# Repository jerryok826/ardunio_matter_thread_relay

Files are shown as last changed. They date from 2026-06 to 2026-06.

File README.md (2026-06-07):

# Matter-over-Thread 4-Channel Intelligent Relay Controller

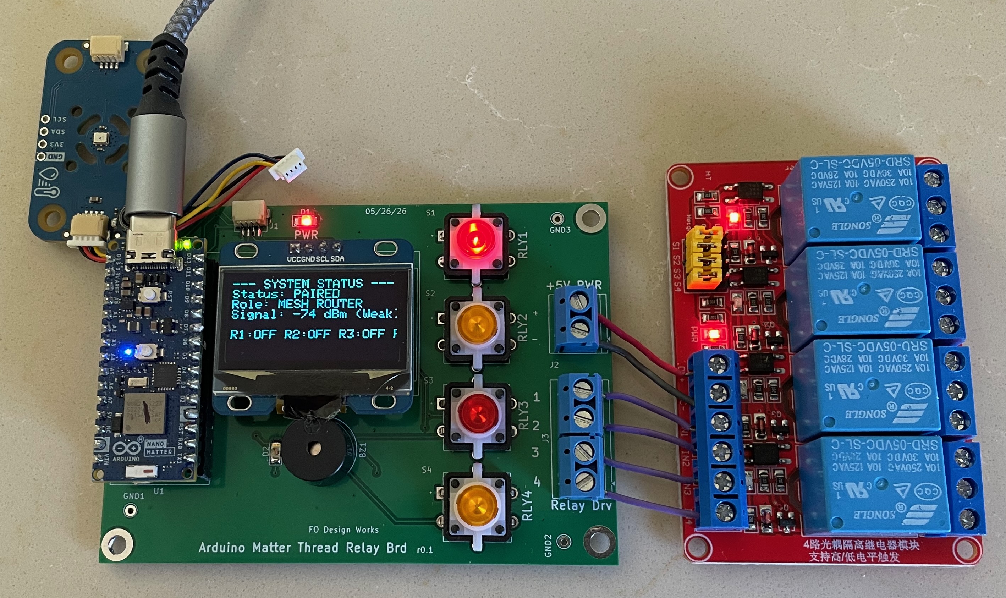
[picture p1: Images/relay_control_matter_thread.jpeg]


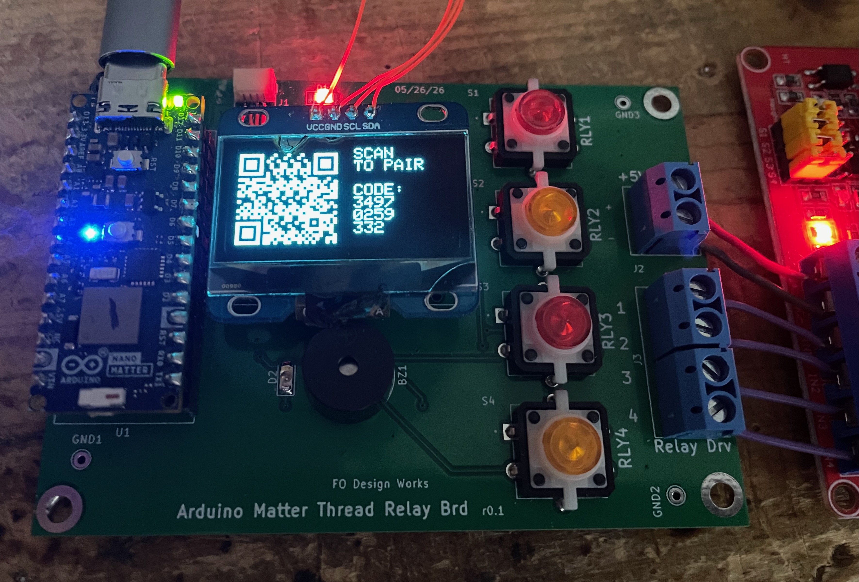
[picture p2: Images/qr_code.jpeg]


The board shown below is an Arduino Matter/Thread relay controller designed for use with an Apple HomeKit network. It uses an Arduino Nano Matter processor to control four onboard relays, which can be used to operate motors, lights, valves, or other electrical loads.

Each relay can be controlled locally using the onboard pushbuttons, allowing users to manually enable or disable individual outputs. Through the Apple Home app on an iPhone, each relay can also be monitored and controlled remotely from anywhere with internet access.

An integrated OLED display provides system status information, including Thread network signal strength. During initial setup, the display presents a QR code that can be scanned to quickly add the device to the Apple Home app.

The board also includes an I²C Qwiic connector for attaching external sensors and peripherals. For example, a rain sensor could be connected to automatically disable irrigation valves during rainfall, helping conserve water and prevent overwatering.

**Status:** The board completely supports relay control. The I²C Qwiic connector is wired wrong. There are other physical placements that need updating. So the board will be turned. Gerber files will be punished after these changes.

An industrial-grade, ultra-low-latency 4-Channel Relay Controller built using the **Arduino Nano Matter** (Silicon Labs MGM240S core). This project connects natively with Apple Home, Home Assistant, and other Matter ecosystems over a self-healing Thread mesh network.

Featuring an asynchronous hardware override architecture, non-blocking FreeRTOS thread watchdogs, and an integrated I2C OLED display that acts as a standalone **RF Survey & Walk-Testing Tool**, this project is designed for robust, long-term smart home panel automation.

---

## ✨ Key Features

- **Ecosystem Unified Build:** Native Matter protocol integration that auto-populates as four independent, sequential switch endpoints in your smart home application.
- **Zero App Dependence Override:** Local manual buttons run entirely on edge-triggered **Asynchronous Hardware Interrupts**. Relays switch locally within microseconds even if your smart home hub is offline or entirely destroyed.
- **Anti-Race Watchdog:** Implements a non-blocking 50ms throttled execution pacing engine to prevent Matter application layer data collisions and loop freezing.
- **Failsafe Boot Protection:** Firmware forces relay pins to an explicit `LOW` state prior to opening output drivers. Combined with physical pull-down networks, this eliminates clicks or accidental appliance cycles during microcontroller reboots.
- **Dual-OLED Matrix Engine:** Dynamic runtime support for both **SH1106** and **SSD1306** I2C displays via a simple preprocessor toggle.
- **Standalone RF Survey Tool:** Displays a dynamic pairing QR code on boot, then transitions automatically into a real-time system dashboard mapping your Thread Node Role and precise signal attenuation metrics (`dBm`) on a fast 3-second cycle.

---

## 🛠️ Hardware Requirements & Pinout

### Core Microcontroller
- [Arduino Nano Matter](https://arduino.cc) (Silicon Labs MGM240S)

### Supported Displays
- 0.96" I2C OLED Display (**SH1106 Recommended** for native border alignment, or SSD1306)

### Physical Netlist Connection Map

| Arduino Pin | Hardware Component | Electrical Specification / Circuit Design |
| :--- | :--- | :--- |
| **D2** | Relay 1 Trigger Output | Active-HIGH Latch (Must use 10kΩ external Pull-Down to GND) |
| **D3** | Relay 2 Trigger Output | Active-HIGH Latch (Must use 10kΩ external Pull-Down to GND) |
| **D4** | Relay 3 Trigger Output | Active-HIGH Latch (Must use 10kΩ external Pull-Down to GND) |
| **D5** | Relay 4 Trigger Output | Active-HIGH Latch (Must use 10kΩ external Pull-Down to GND) |
| **D6** | Manual Button 1 Input | Short-to-GND Momentary Switch (Relies on internal `INPUT_PULLUP`) |
| **D7** | Manual Button 2 Input | Short-to-GND Momentary Switch (Relies on internal `INPUT_PULLUP`) |
| **D8** | Manual Button 3 Input | Short-to-GND Momentary Switch (Relies on internal `INPUT_PULLUP`) |
| **D9** | Manual Button 4 Input | Short-to-GND Momentary Switch (Relies on internal `INPUT_PULLUP`) |
| **A4 / SDA**| OLED Serial Data Line | I2C Data (Include physical 4.7kΩ external Pull-Up to 3.3V) |
| **A5 / SCL**| OLED Serial Clock Line | I2C Clock (Include physical 4.7kΩ external Pull-Up to 3.3V) |
| **BTN_BUILTIN**| Factory Reset Trigger | Physical button on Nano Matter. Hold 10s to wipe Matter Fabric. |

> ⚠️ **CRITICAL DEVELOPER WARNING:** The Arduino Nano Matter GPIO pins safely output a maximum of **4mA to 8mA**. Standard mechanical relay coils draw between **70mA and 100mA**. **Do not wire relay coils directly to the Arduino pins.** You must use transistor switches (e.g., 2N2222) or optocouplers (e.g., PC817) on your custom PCB to isolate the driver currents.

---

## 💻 Firmware Installation & Configuration

### 1. Prerequisites
Ensure your Arduino IDE environment is properly updated:
1. Open the Arduino IDE, go to **Tools > Board > Boards Manager** and install the **Arduino Nano Matter** board package.
2. Go to **Tools > Manage Libraries** and install these exact dependencies:
   - `SSD1306Ascii` (by Bill Greiman)
   - `QRCode` (by Richard Moore)

### 2. IDE Compilation Configuration
Before flashing the firmware, you **must** configure the low-level stack settings:
- Go to **Tools > Protocol Stack** and select **Matter**. 
- *Note: If this is left on "None", the compiler will completely ignore all Matter initialization sequences.*

### 3. Display Selection Toggle
At the very top of the primary sketch file, uncomment the specific preprocessor definition that matches your physical OLED module hardware:

```cpp
// UNCOMMENT ONLY ONE of the options below to match your physical OLED panel:
#define DISPLAY_TYPE_SH1106      // Use this if your screen has an SH1106 controller
// #define DISPLAY_TYPE_SSD1306  // Use this if your screen has a true SSD1306 controller
```

---

## 📱 Provisioning & First-Time Setup

1. Flash the firmware to your board and open your serial monitor at **115200 baud**.
2. Upon boot, the board will automatically check its secure enclave storage rows. If it is uncommissioned, a custom **Version 3 QR Matrix** will automatically render on the left side of your OLED screen.
3. Open your native smart home app (e.g., **Apple Home**) on your iPhone.
4. Tap **Add Accessory** and point your camera at the OLED glass panel.
5. **Alternative Manual Flow:** If the camera cannot capture the display grid due to enclosure glare, tap *More Options / I Don't Have a Code*, select the module from the nearby Bluetooth list, and manually input the static 11-digit setup passcode:
   ```text
   Manual Setup Code: 3497-0259-332
   ```
6. Keep your phone close to the hardware for the first 30 seconds. The initial handshake executes over Bluetooth Low Energy (BLE) before moving the board permanently to your home's **Thread Mesh Network**.

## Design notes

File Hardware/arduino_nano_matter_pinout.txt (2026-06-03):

Module:Arduino_Nano pin out

Left Side (Pins 1–15, Antenna heading UP to USB-C)
Pin 1: D0 / TX1 (Right next to the RF Antenna)
Pin 2: D1 / RX1
Pin 3: ~RST (Reset Input)
Pin 4: GND (Ground)
Pin 5: D2
Pin 6: D3
Pin 7: D4
Pin 8: D5
Pin 9: D6
Pin 10: D7
Pin 11: D8
Pin 12: D9
Pin 13: D10
Pin 14: D11
Pin 15: D12 (Top-left corner pin right next to the USB-C port)
Right Side (Pins 16–30, USB-C heading DOWN to Antenna)
Pin 16: D13 (Top-right corner pin right next to the USB-C port)
Pin 17: +3.3V (Regulated Power Output)
Pin 18: AREF (Analog Reference Reference)
Pin 19: A0 (First Analog Input)
Pin 20: A1
Pin 21: A2
Pin 22: A3
Pin 23: A4 / SDA
Pin 24: A5 / SCL
Pin 25: A6
Pin 26: A7
Pin 27: +5V (Regulated 5V Output or USB Bus Power Input)
Pin 28: NC
Pin 29: GND (Ground 2)
Pin 30: VIN (Unregulated Power Input, bottom-right across from Pin 1)

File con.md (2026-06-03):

# Contributing to the Matter-over-Thread Relay Controller

First off, thank you for taking the time to contribute! This project is open-source, and contributions from the community help make this firmware more resilient, feature-rich, and reliable for long-term smart home industrial deployments.

As an embedded development project handling real-time networks (Matter/Thread) and low-level hardware constraints, please review the following guidelines before opening a pull request (PR).

---

## 🛡️ Core Architecture Constraints (Do Not Break)

The firmware in this repository has been heavily optimized to run reliably in an asynchronous, multi-threaded FreeRTOS environment. To ensure stability, all contributions must respect the following architectural constraints:

### 1. Strictly Non-Blocking Execution
- **Never add blocking `delay()` statements anywhere inside the `loop()` or peripheral handlers.** 
- The background Silicon Labs OpenThread engine relies on microsecond-level timing windows. Introducing blocking code starves the network stack, causing dynamic packet drops, frozen status registers, and sudden "No Response" errors in home automation applications.
- Always implement timing intervals using non-blocking tracking variables combined with `millis()` checks.

### 2. Microsecond-Level ISR Isolation
- Keep Hardware Interrupt Service Routines (`pin6_ISR` through `pin9_ISR`) as lightweight as possible. 
- Do not run calculations, serial printing, or display routines inside an active ISR thread. Simply set the volatile state tracking flag (`buttonFlags[i] = true;`) and exit, allowing the main runtime loop to handle physical pin execution.

### 3. Asynchronous Data Coupling & Throttling
- Matter network state updates (`get_onoff()`) occur asynchronously in a low-priority background thread. 
- Any code evaluating or polling smart home network clusters must operate inside a throttled window (configured natively to **50ms**). Unthrottled continuous querying forces memory race conditions, dropping local physical button signals.
- Decouple local physical pins from over-the-air network commands by using the established `shadowMatterStates` tracking array layout to filter out redundant execution loops.

---

## 🔧 Workflow Guidelines

### 1. Code Style & Conventions
- Maintain the **Manual Code Version Tracker** block at the top of the sketch to flag project iterations cleanly during debugging.
- Explicitly pass specific index boundaries (such as `[i]`) across all conditional loops and hardware array mappings. Avoid comparisons that force array decay into raw pointers, which fail silently on compilation check gates.
- Comment any adjustments made to low-level OpenThread system registers (`otInstanceInitSingle()`, etc.) to specify the network safety layout impact.

### 2. Testing Your Submissions
Before committing code or submitting a PR, your build must pass the following benchmark checks on a physical target board:
1. **Compilation Check:** Confirm the sketch compiles with zero warnings or token formatting errors in the Arduino IDE under the target board profile.
2. **Ecosystem Sync Test:** Verify that cycling a local physical push-button immediately mirrors the correct toggle state on your app dashboard within 100ms.
3. **RF Walk-Test Verification:** Ensure the 3-second non-blocking display loop updates the active dBm neighbor data accurately without stalling the local mechanical relay contacts.
4. **Decommission Safety Profile:** Verify that holding the physical user button for 10 full seconds forcefully triggers a clean fabric wipe and triggers a clean hardware system reset (`NVIC_SystemReset()`).

### 3. Opening a Pull Request
- Create a distinct topic branch for your feature or patch. Do not submit changes directly to the `main` branch.
- Structure your commit messages clearly (e.g., `fix: add explicit array indexing boundary to loop validation tracker`).
- Describe the exact hardware setup, display module configuration type (SH1106 or SSD1306), and automation hub you used during testing in your PR summary notes.

---

## 📜 Code of Conduct

By participating in this project, you agree to treat all contributors with respect, provide constructive technical feedback during code reviews, and promote collaborative open-source engineering.

Thank you for helping optimize this intelligent Matter relay node footprint!

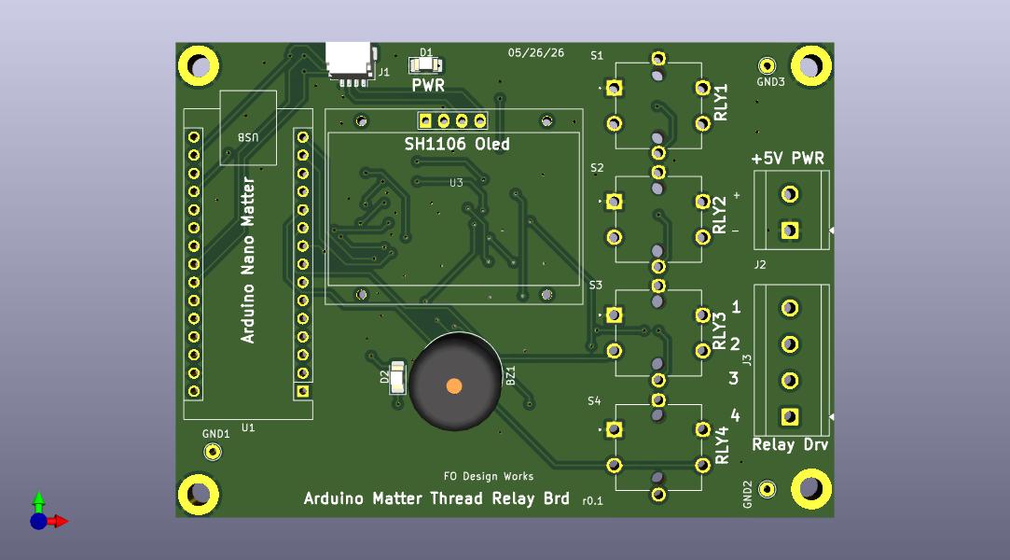
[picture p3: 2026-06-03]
Hardware/matter_thread_relay_r1.jpg

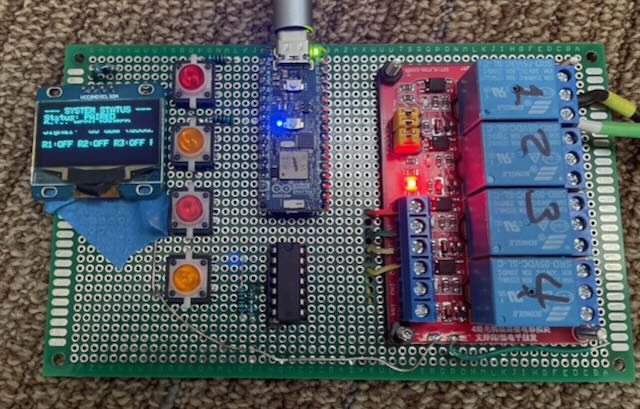
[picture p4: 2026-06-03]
Images/matter_thread_relay_3.jpeg

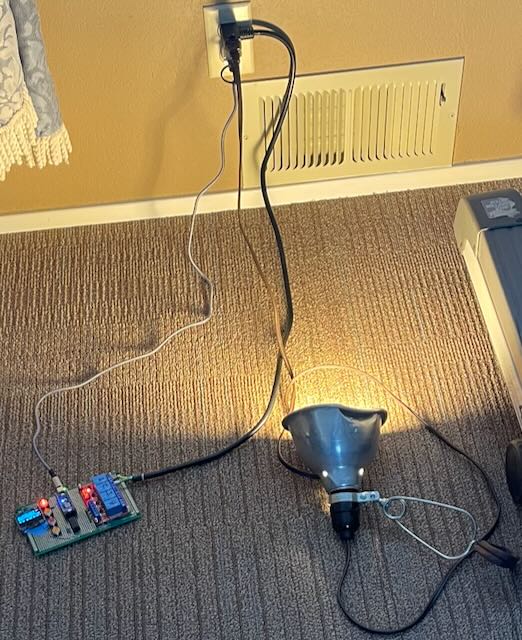
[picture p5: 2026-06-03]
Images/matter_thread_relay_4.jpeg

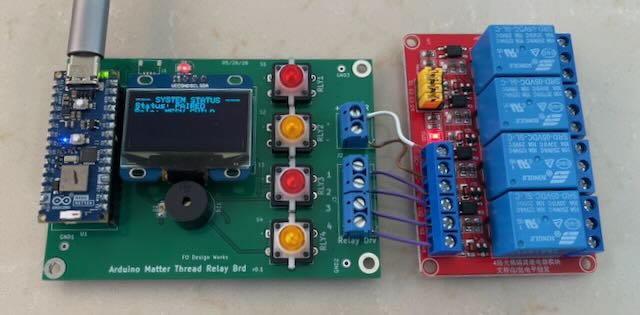
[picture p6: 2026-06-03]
Images/matter_thread_relay_1.jpeg

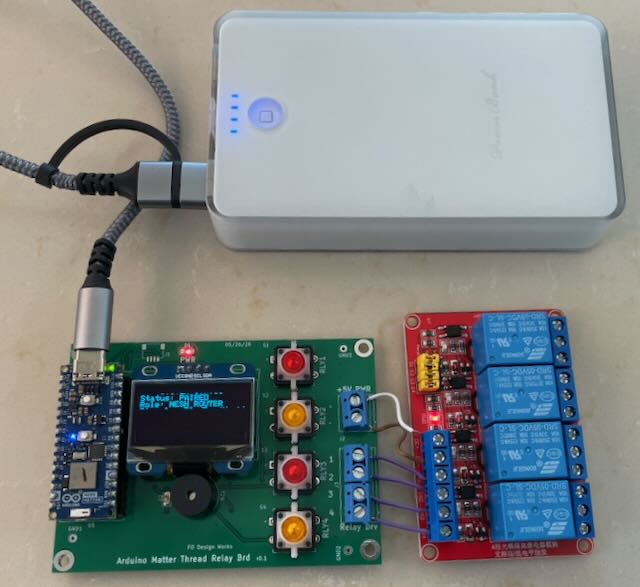
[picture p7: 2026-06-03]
Images/matter_thread_relay_2.jpeg

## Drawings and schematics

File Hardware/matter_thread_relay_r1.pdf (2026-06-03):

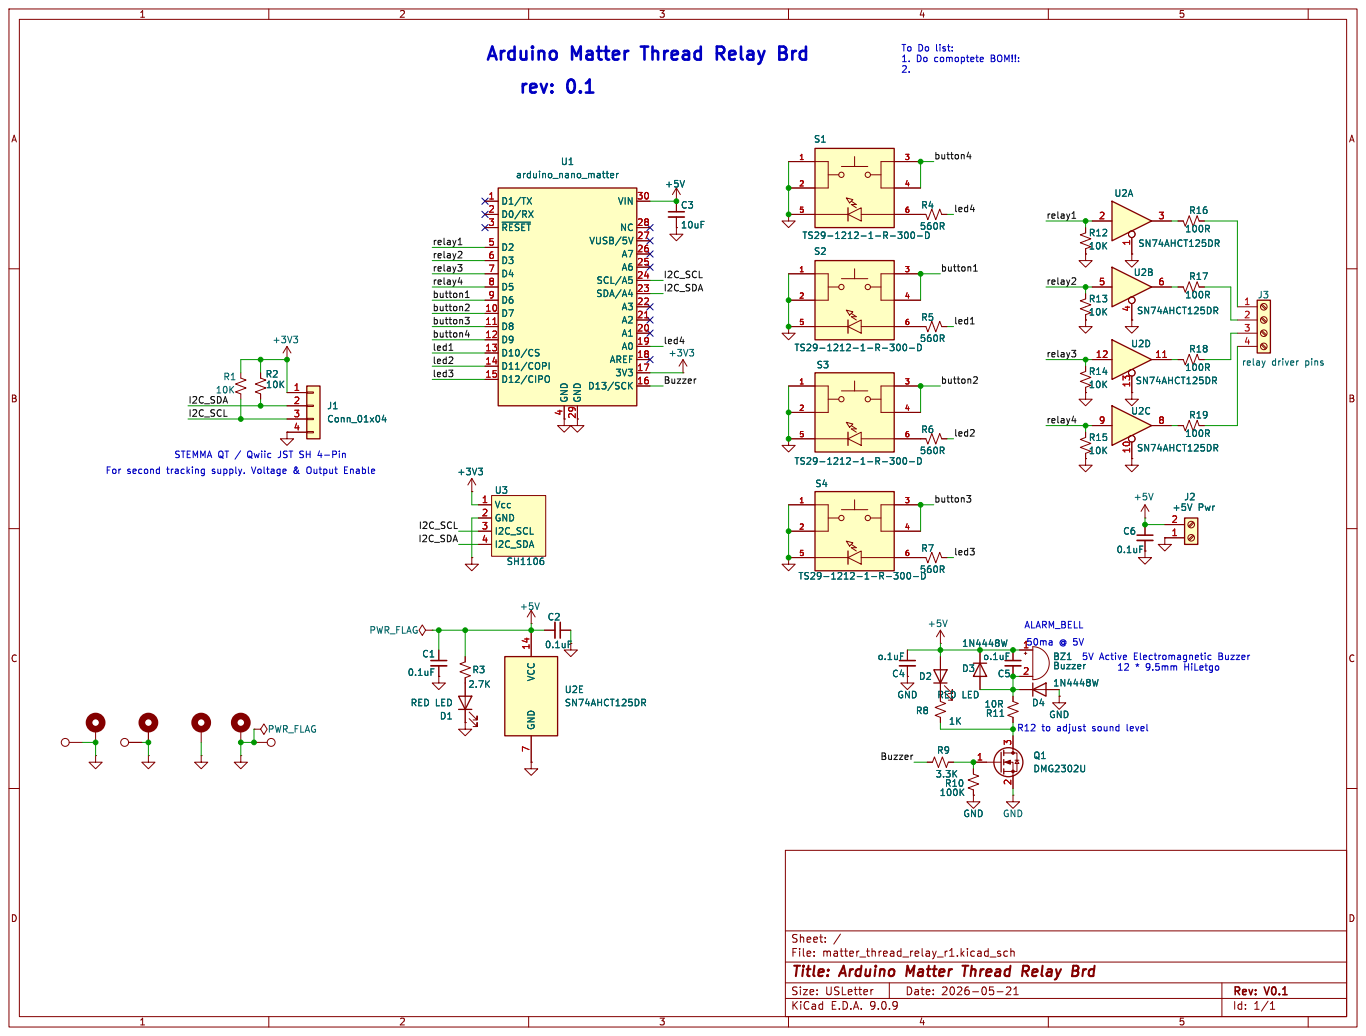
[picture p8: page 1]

button4 Buzzer Buzzer Arduino Matter Thread Relay Brd
rev: 0.1

4 GND 29 VIN 30 NC 28 VUSB/5V 27 A7 26 A6 25 SCL/A5 24 SDA/A4 23 A3 22 A2 21 A1 20 A0 19 AREF 18

STEMMA QT / Qwiic JST SH 4-Pin

File: matter_thread_relay_r1.kicad_sch Sheet: /
Id: 1/1 Title: Arduino Matter Thread Relay Brd

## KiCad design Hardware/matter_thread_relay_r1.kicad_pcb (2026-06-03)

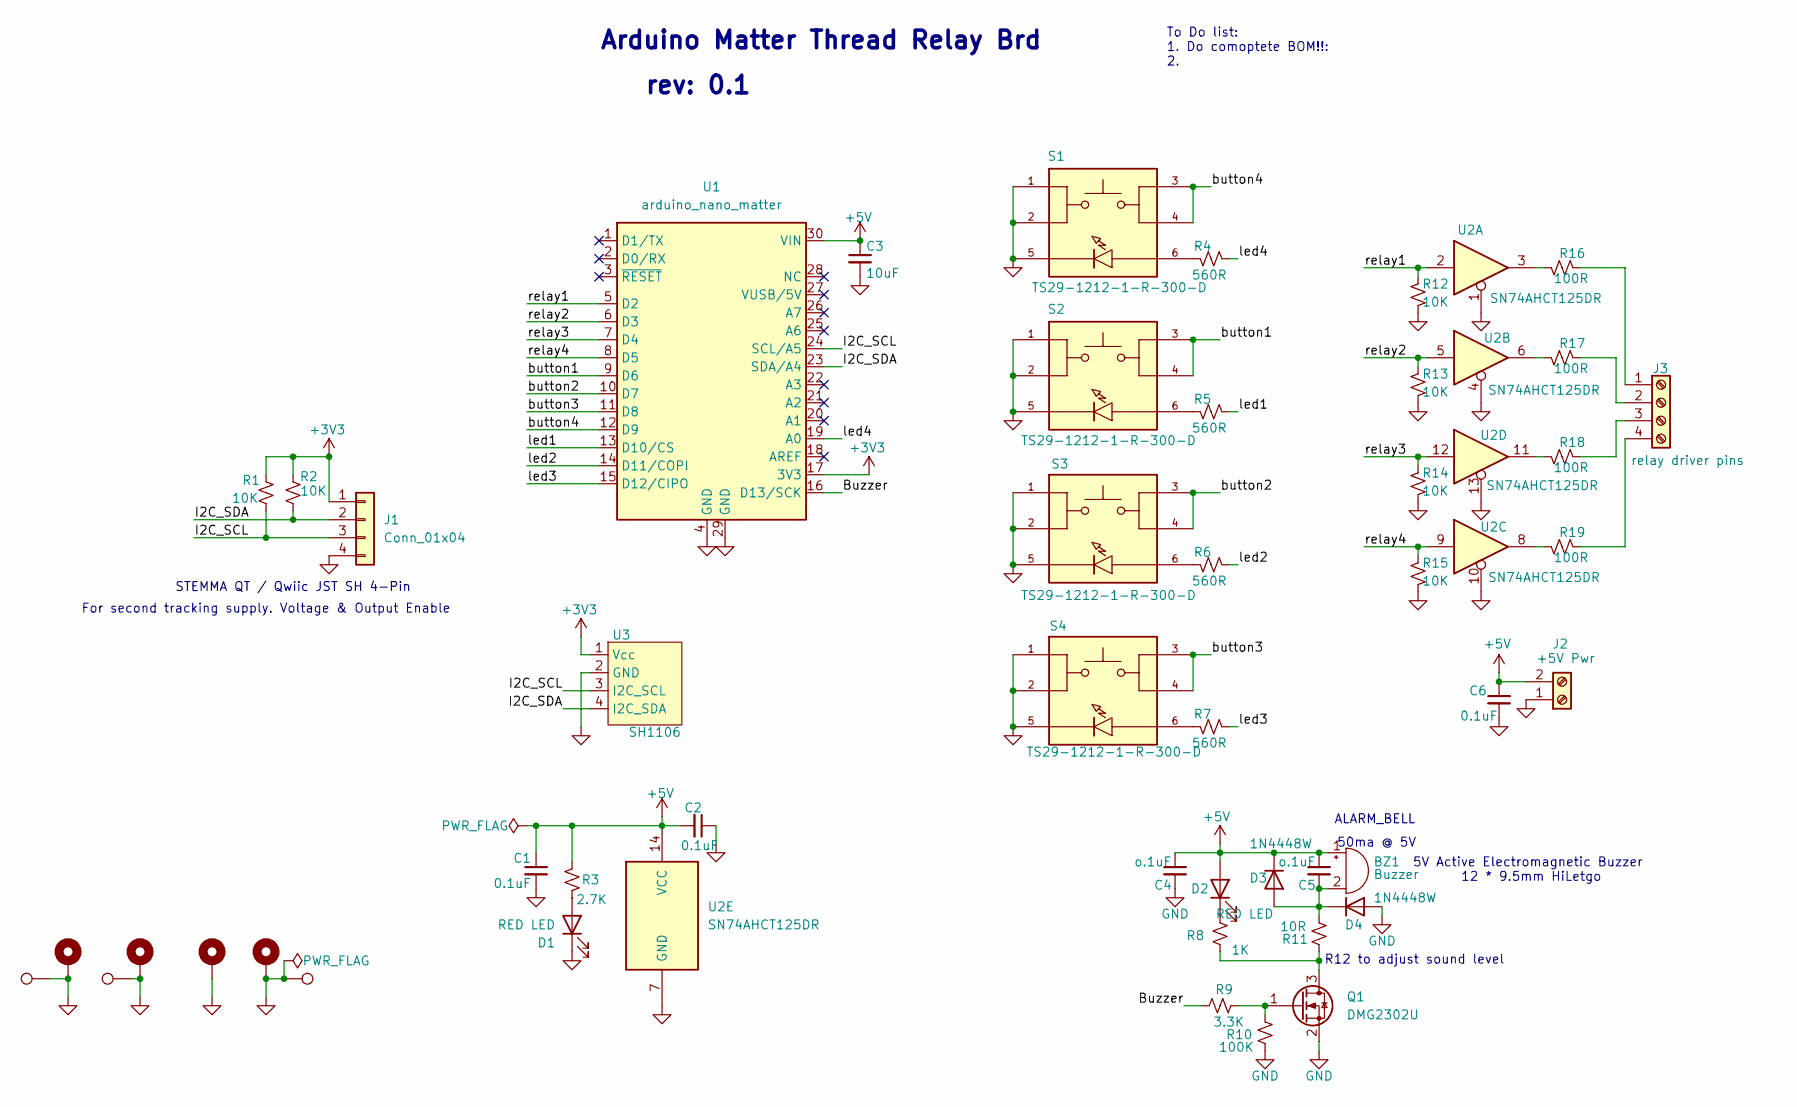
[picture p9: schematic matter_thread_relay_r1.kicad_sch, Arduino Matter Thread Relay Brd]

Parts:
BZ1: Buzzer; Buzzer_12x9.5RM7.6
C1, C2, C6: 0.1uF; C_0805_2012Metric_Pad1.18x1.45mm_HandSolder
C3: 10uF; C_0805_2012Metric_Pad1.18x1.45mm_HandSolder
C4, C5: o.1uF; C_0805_2012Metric_Pad1.18x1.45mm_HandSolder
D1, D2: RED LED; LED_1206_3216Metric_Pad1.42x1.75mm_HandSolder
D3, D4: 1N4448W; D_SOD-123
GND1, GND2, GND3: GND; TestPoint_THTPad_D2.0mm_Drill1.0mm
H1, H2, H4, H6: MountingHole_Pad; MountingHole_3.2mm_M3_ISO7380_Pad_TopBottom
J1: Conn_01x04; JST_SH_SM04B-SRSS-TB_1x04-1MP_P1.00mm_Horizontal
J2: +5V Pwr; TerminalBlock_CUI_TB007-508-02_1x02_P5.08mm_Horizontal
J3: relay driver pins; TerminalBlock_CUI_TB007-508-04_1x04_P5.08mm_Horizontal
Q1: DMG2302U; SOT-23
R1, R2, R12, R13, R14, R15: 10K; R_0805_2012Metric_Pad1.20x1.40mm_HandSolder
R3: 2.7K; R_0805_2012Metric_Pad1.20x1.40mm_HandSolder
R4, R5, R6, R7: 560R; R_0805_2012Metric_Pad1.20x1.40mm_HandSolder
R8: 1K; R_0805_2012Metric_Pad1.20x1.40mm_HandSolder
R9: 3.3K; R_0805_2012Metric_Pad1.20x1.40mm_HandSolder
R10: 100K; R_0805_2012Metric_Pad1.20x1.40mm_HandSolder
R11: 10R; R_0805_2012Metric_Pad1.20x1.40mm_HandSolder
R16, R17, R18, R19: 100R; R_0805_2012Metric_Pad1.20x1.40mm_HandSolder
S1, S2, S3, S4: TS29-1212-1-R-300-D; SW_TS29-1212-1-R-300-D; PARTREV 1.01
U1: arduino_nano_matter; Arduino_Nano
U2: SN74AHCT125DR; SO-14_5.3x10.2mm_P1.27mm
U3: SH1106

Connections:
+3V3: J1.1, R1.2, R2.2, U1.17 (3V3), U3.1 (Vcc)
+5V: BZ1.1 (+), C1.1, C2.2, C3.1, C4.1, C5.1, C6.1, D2.2 (A), D3.1 (K), J2.2, R3.2, U1.30 (VIN), U2.14 (VCC)
/Buzzer: R9.2, U1.16 (D13/SCK)
/I2C_SCL: J1.3, R1.1, U1.24 (SCL/A5), U3.3 (I2C_SCL)
/I2C_SDA: J1.2, R2.1, U1.23 (SDA/A4), U3.4 (I2C_SDA)
/button1: S2.3, S2.4, U1.9 (D6)
/button2: S3.3, S3.4, U1.10 (D7)
/button3: S4.3, S4.4, U1.11 (D8)
/button4: S1.3, S1.4, U1.12 (D9)
/led1: R5.1, U1.13 (D10/CS)
/led2: R6.1, U1.14 (D11/COPI)
/led3: R7.1, U1.15 (D12/CIPO)
/led4: R4.1, U1.19 (A0)
/relay1: R12.2, U1.5 (D2), U2.2
/relay2: R13.2, U1.6 (D3), U2.5
/relay3: R14.2, U1.7 (D4), U2.12
/relay4: R15.2, U1.8 (D5), U2.9
GND: C1.2, C2.1, C3.2, C4.2, C6.2, D1.1 (K), D4.2 (A), GND1.1, GND2.1, GND3.1, H1.1, H2.1, H4.1, H6.1, J1.4, J2.1, Q1.2 (S), R10.2, R12.1, R13.1, R14.1, R15.1, S1.1, S1.2, S1.5, S2.1, S2.2, S2.5, S3.1, S3.2, S3.5, S4.1, S4.2, S4.5, U1.4 (GND), U1.29 (GND), U2.1, U2.4, U2.7 (GND), U2.10, U2.13, U3.2 (GND)
unnamed: BZ1.2 (-), C5.2, D3.2 (A), D4.1 (K), R11.1
unnamed: D1.2 (A), R3.1
unnamed: D2.1 (K), R8.1
unnamed: J3.1, R16.1
unnamed: J3.2, R17.1
unnamed: J3.3, R18.1
unnamed: J3.4, R19.1
unnamed: Q1.3 (D), R8.2, R11.2
unnamed: Q1.1 (G), R9.1, R10.1
unnamed: R4.2, S1.6
unnamed: R5.2, S2.6
unnamed: R6.2, S3.6
unnamed: R7.2, S4.6
unnamed: R16.2, U2.3
unnamed: R17.2, U2.6
unnamed: R18.2, U2.11
unnamed: R19.2, U2.8

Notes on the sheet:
To Do list: 1. Do comoptete BOM!!: 2.
rev: 0.1
For second tracking supply. Voltage & Output Enable
5V Active Electromagnetic Buzzer 12 * 9.5mm HiLetgo
Arduino Matter Thread Relay Brd
ALARM_BELL
STEMMA QT / Qwiic JST SH 4-Pin
R12 to adjust sound level
50ma @ 5V

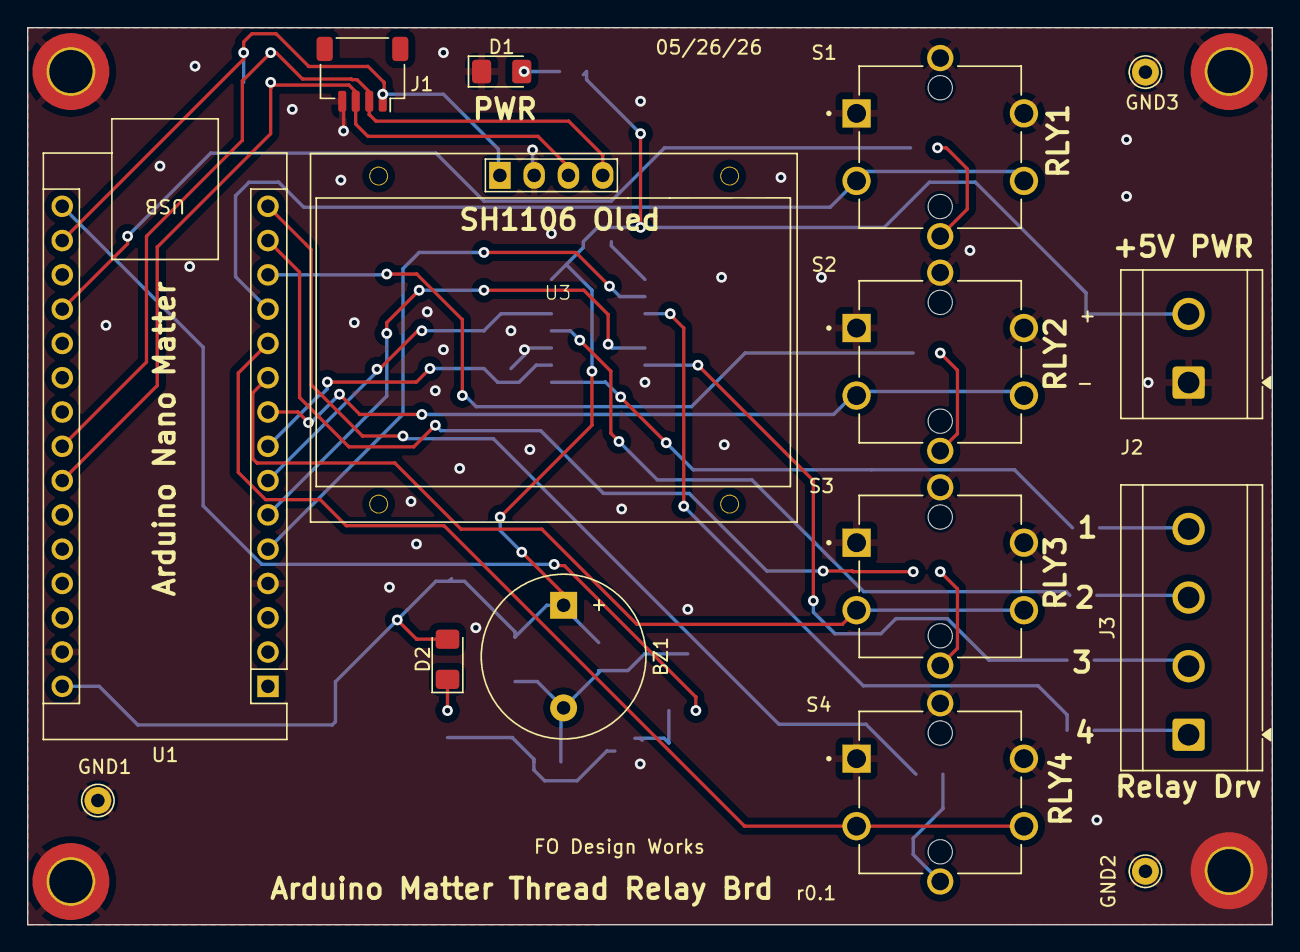
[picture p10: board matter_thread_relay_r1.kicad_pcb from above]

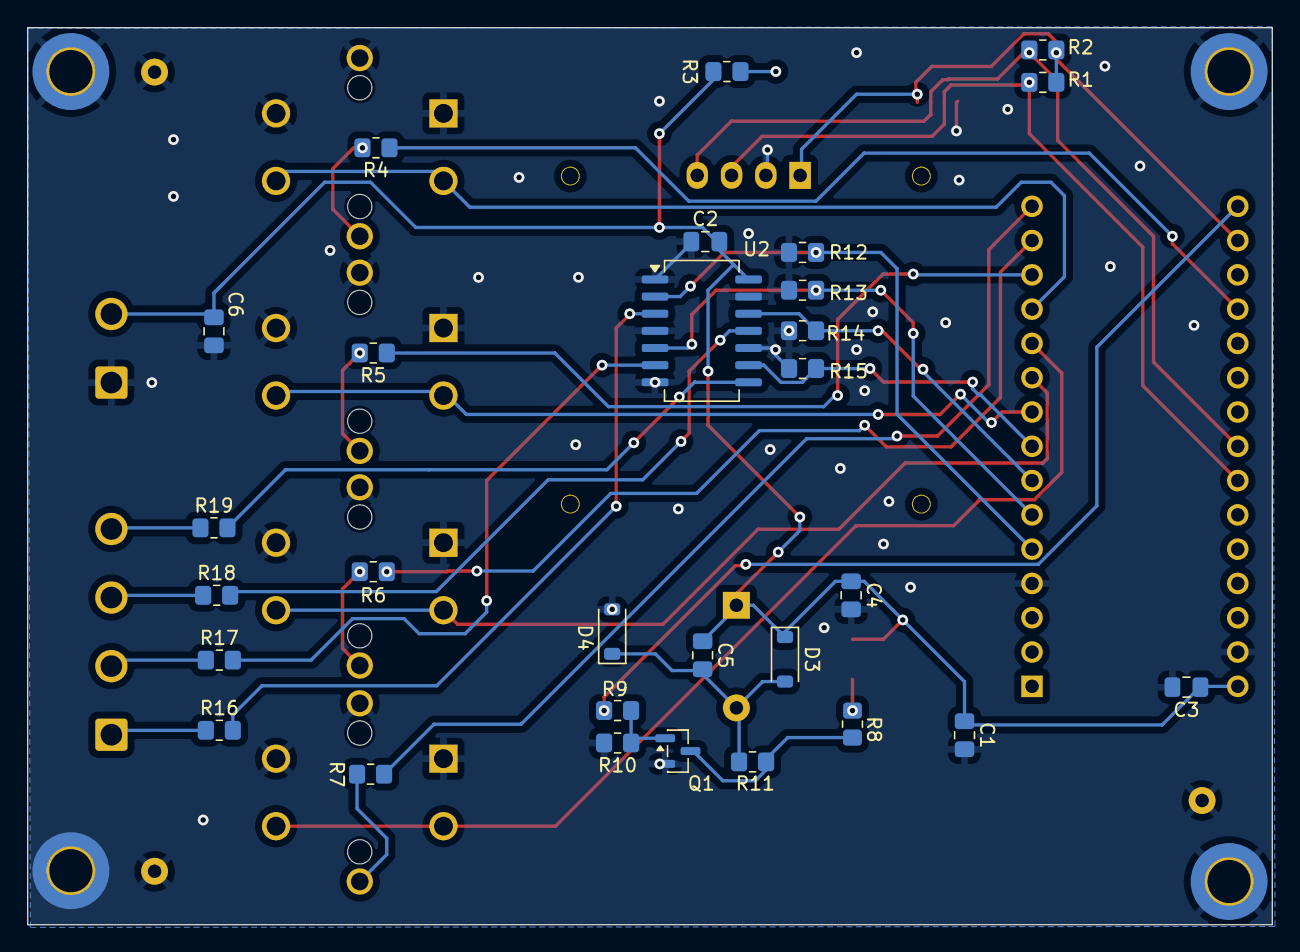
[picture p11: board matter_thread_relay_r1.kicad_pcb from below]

Board: 2 copper layers, 92.2 x 66.4 mm, 48 parts (29 on the bottom side), 35 nets.

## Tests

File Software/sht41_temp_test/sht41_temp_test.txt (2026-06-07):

// Arduino Nano Matter code to read an Temperature & Humidity Sensor(SHT41) sensor over I2C via the Qwiic connector and print data to the serial port."
// To verfy the I2C Qwiic connection.

#include <Arduino.h>
#include <Wire.h>
#include <Adafruit_SHT4x.h>

Adafruit_SHT4x sht4 = Adafruit_SHT4x();

void setup() {
  // Initialize Serial Monitor
  Serial.begin(115200);
  while (!Serial) {
    delay(10); // Wait for serial port to connect
  }

  Serial.println("SHT41 Test - Nano Matter");

  // Initialize the SHT4x sensor
  if (!sht4.begin()) {
    Serial.println("Couldn't find SHT4x sensor. Check your wiring!");
    while (1) delay(1);
  }

  Serial.println("Found SHT4x sensor!");

  // Set precision to High (you can also use SHT4X_MED_PRECISION or SHT4X_LOW_PRECISION)
  sht4.setPrecision(SHT4X_HIGH_PRECISION);
  
  // Set heater to activate for testing
  sht4.setHeater(SHT4X_NO_HEATER);
}

void loop() {
  sensors_event_t humidity, temp;

  // Get event with current sensor reading
  sht4.getEvent(&humidity, &temp);

  // Print temperature to Serial
  Serial.print("Temperature: ");
  Serial.print(temp.temperature);
  Serial.println(" °C");

  // Print humidity to Serial
  Serial.print("Humidity:    ");
  Serial.print(humidity.relative_humidity);
  Serial.println(" %");

  Serial.println("------------------------");

  // Wait 1 second between readings
  delay(1000);
}

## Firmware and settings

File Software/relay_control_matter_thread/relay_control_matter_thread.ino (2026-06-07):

#include <Matter.h>
#include <MatterOnOffPluginUnit.h>
#include <openthread/thread.h>
#include <openthread/instance.h>

#include <Wire.h>
#include "SSD1306Ascii.h"
#include "SSD1306AsciiWire.h"
#include "qrcode.h"

#define CHIP_DEVICE_CONFIG_DEVICE_VENDOR_ID   0xFFF2
#define CHIP_DEVICE_CONFIG_DEVICE_PRODUCT_ID  0x8001

const char* CODE_CREATION_TIMESTAMP = "Friday May 22, 2026 - 02:30 PM";

const int relayPins[]  = {D2, D3, D4, D5};
const int buttonPins[] = {D6, D7, D8, D9};
const int ledPins[]    = {D10, D11, D12, A0};
const int buzzerPin = D13;

bool relayStates[] = {LOW, LOW, LOW, LOW};
bool shadowMatterStates[] = {LOW, LOW, LOW, LOW};
bool bootSyncCompleted = false;

volatile bool buttonFlags[] = {false, false, false, false};
unsigned long lastInterruptTime[] = {0, 0, 0, 0};
const unsigned long debounceDelay = 250;

unsigned long lastNetworkCheckTime = 0;
const unsigned long networkCheckInterval = 3000;

unsigned long lastBlinkTime = 0;
bool blinkState = false;

unsigned long lastNetworkPollTime = 0;
const unsigned long networkPollInterval = 50;

SSD1306AsciiWire oled;

MatterOnOffPluginUnit matterRelay1;
MatterOnOffPluginUnit matterRelay2;
MatterOnOffPluginUnit matterRelay3;
MatterOnOffPluginUnit matterRelay4;

void updateOLEDUI();

void pin6_ISR() {
  if (millis() - lastInterruptTime[0] > debounceDelay) {
    buttonFlags[0] = true;
    lastInterruptTime[0] = millis();
  }
}

void pin7_ISR() {
  if (millis() - lastInterruptTime[1] > debounceDelay) {
    buttonFlags[1] = true;
    lastInterruptTime[1] = millis();
  }
}

void pin8_ISR() {
  if (millis() - lastInterruptTime[2] > debounceDelay) {
    buttonFlags[2] = true;
    lastInterruptTime[2] = millis();
  }
}

void pin9_ISR() {
  if (millis() - lastInterruptTime[3] > debounceDelay) {
    buttonFlags[3] = true;
    lastInterruptTime[3] = millis();
  }
}

void playResetBeep() {
  digitalWrite(buzzerPin, HIGH);
  delay(50);
  digitalWrite(buzzerPin, LOW);
}

void playPairingSuccessBeep() {
  digitalWrite(buzzerPin, HIGH);
  delay(100);
  digitalWrite(buzzerPin, LOW);
  delay(50);
  digitalWrite(buzzerPin, HIGH);
  delay(100);
  digitalWrite(buzzerPin, LOW);
}

bool isThreadMeshActive() {
  otInstance* instance = otInstanceInitSingle();
  if (instance == NULL) return false;

  otDeviceRole role = otThreadGetDeviceRole(instance);
  return (role == OT_DEVICE_ROLE_CHILD || role == OT_DEVICE_ROLE_ROUTER);
}

void updateNetworkStatusLED() {
  if (Matter.isDeviceCommissioned()) {
    digitalWrite(LEDB, LOW);
  } else {
    if (millis() - lastBlinkTime >= 500) {
      lastBlinkTime = millis();
      blinkState = !blinkState;
      digitalWrite(LEDB, blinkState ? LOW : HIGH);
    }
  }
}

void logAndSwitch(int index, bool newState, const char* source) {
  relayStates[index] = newState;

  digitalWrite(relayPins[index], newState);
  digitalWrite(ledPins[index], newState);

  Serial.print("[");
  Serial.print(source);
  Serial.print("] Relay ");
  Serial.print(index + 1);
  Serial.println(newState ? " -> ON" : " -> OFF");

  updateOLEDUI();
}

// ======================================================================
// FIXED QR DRAWING FUNCTION
//
// Keeps SSD1306Ascii.
// Does not use Adafruit_GFX.
// Draws raw pixels only during pairing.
// QR version 3 = 29 x 29 modules.
// Scale 2 = 58 x 58 pixels, fits 128 x 64 OLED.
// ======================================================================
void drawOnboardQRCode(const char* qrDataString) {
  QRCode qrcode;

  const uint8_t qrVersion = 3;
  const uint8_t scale = 2;

  const uint8_t qrX = 2;
  const uint8_t qrY = 3;

  uint8_t qrcodeData[qrcode_getBufferSize(qrVersion)];
  qrcode_initText(&qrcode, qrcodeData, qrVersion, ECC_LOW, qrDataString);

  oled.clear();

  const uint8_t qrPixelSize = qrcode.size * scale;

  for (uint8_t page = 0; page < 8; page++) {
    oled.setCol(qrX);
    oled.setRow(page);

    for (uint8_t px = 0; px < qrPixelSize; px++) {
      uint8_t dataByte = 0;

      for (uint8_t bit = 0; bit < 8; bit++) {
        uint8_t py = page * 8 + bit;

        if (py >= qrY && py < qrY + qrPixelSize) {
          uint8_t qrModuleX = px / scale;
          uint8_t qrModuleY = (py - qrY) / scale;

          if (qrcode_getModule(&qrcode, qrModuleX, qrModuleY)) {
            dataByte |= (1 << bit);
          }
        }
      }

      oled.ssd1306WriteRam(dataByte);
    }

    delay(1);
  }

  oled.setFont(Adafruit5x7);

  oled.setCursor(70, 0);
  oled.print("SCAN");

  oled.setCursor(70, 1);
  oled.print("TO PAIR");

  oled.setCursor(70, 3);
  oled.print("CODE:");

  oled.setCursor(70, 4);
  oled.print("3497");

  oled.setCursor(70, 5);
  oled.print("0259");

  oled.setCursor(70, 6);
  oled.print("332");
}

void updateOLEDUI() {
  if (!Matter.isDeviceCommissioned()) {
    return;
  }

  oled.clear();
  oled.setFont(Adafruit5x7);

  oled.setCol(0);
  oled.println("--- SYSTEM STATUS ---");

  oled.setCol(0);
  oled.println("Status: PAIRED");

  otInstance* instance = otInstanceInitSingle();
  int8_t rssiValue = -127;

  if (instance != NULL) {
    otDeviceRole role = otThreadGetDeviceRole(instance);

    oled.setCol(0);
    oled.print("Role: ");

    if (role == OT_DEVICE_ROLE_DETACHED) {
      oled.println("SCANNING...");
    } else if (role == OT_DEVICE_ROLE_CHILD) {
      oled.println("MESH CHILD");
      otThreadGetParentLastRssi(instance, &rssiValue);
    } else if (role == OT_DEVICE_ROLE_ROUTER) {
      oled.println("MESH ROUTER");

      otNeighborInfoIterator iterator = OT_NEIGHBOR_INFO_ITERATOR_INIT;
      otNeighborInfo neighborInfo;

      if (otThreadGetNextNeighborInfo(instance, &iterator, &neighborInfo) == OT_ERROR_NONE) {
        rssiValue = neighborInfo.mAverageRssi;
      }
    } else {
      oled.println("OFFLINE");
    }

    oled.setCol(0);
    oled.print("Signal: ");

    if (!isThreadMeshActive()) {
      oled.println("LOST LINK");
    } else {
      oled.print(rssiValue);
      oled.print(" dBm (");

      if (rssiValue >= -55) {
        oled.println("Max)");
      } else if (rssiValue >= -72) {
        oled.println("Good)");
      } else if (rssiValue >= -85) {
        oled.println("Weak)");
      } else {
        oled.println("Drop)");
      }
    }
  }

  oled.println("");
  oled.setCol(0);

  oled.print("R1:");
  oled.print(relayStates[0] ? "ON " : "OFF");

  oled.print(" R2:");
  oled.print(relayStates[1] ? "ON " : "OFF");

  oled.print(" R3:");
  oled.print(relayStates[2] ? "ON " : "OFF");

  oled.print(" R4:");
  oled.print(relayStates[3] ? "ON " : "OFF");
}

void setup() {
  delay(3000);
  Serial.begin(115200);

  pinMode(buzzerPin, OUTPUT);
  digitalWrite(buzzerPin, LOW);

  playPairingSuccessBeep();

  Wire.begin();
  Wire.setClock(400000);

  oled.begin(&SH1106_128x64, 0x3C);
  oled.clear();
  oled.setFont(Adafruit5x7);
  oled.println("BOOTING HARDWARE...");

  for (int i = 0; i < 4; i++) {
    pinMode(relayPins[i], OUTPUT);
    digitalWrite(relayPins[i], LOW);

    pinMode(ledPins[i], OUTPUT);
    digitalWrite(ledPins[i], LOW);

    pinMode(buttonPins[i], INPUT_PULLUP);
  }

  pinMode(BTN_BUILTIN, INPUT_PULLUP);

  pinMode(LEDR, OUTPUT);
  pinMode(LEDB, OUTPUT);

  digitalWrite(LEDR, HIGH);
  digitalWrite(LEDB, HIGH);

  attachInterrupt(digitalPinToInterrupt(D6), pin6_ISR, FALLING);
  attachInterrupt(digitalPinToInterrupt(D7), pin7_ISR, FALLING);
  attachInterrupt(digitalPinToInterrupt(D8), pin8_ISR, FALLING);
  attachInterrupt(digitalPinToInterrupt(D9), pin9_ISR, FALLING);

  Matter.begin();

  matterRelay1.begin();
  matterRelay2.begin();
  matterRelay3.begin();
  matterRelay4.begin();
}

void loop() {
  unsigned long currentMillis = millis();

  if (!bootSyncCompleted && currentMillis > 4000) {
    bootSyncCompleted = true;

    shadowMatterStates[0] = relayStates[0] = matterRelay1.get_onoff();
    shadowMatterStates[1] = relayStates[1] = matterRelay2.get_onoff();
    shadowMatterStates[2] = relayStates[2] = matterRelay3.get_onoff();
    shadowMatterStates[3] = relayStates[3] = matterRelay4.get_onoff();

    if (!Matter.isDeviceCommissioned()) {
      String qrUrl = Matter.getOnboardingQRCodeUrl();
      String qrPayload = qrUrl;

      if (qrPayload.indexOf("data=") != -1) {
        qrPayload = qrPayload.substring(qrPayload.indexOf("data=") + 5);
      } else {
        qrPayload = "MT:Y.1X040000KA0648300";
      }

      Serial.println();
      Serial.println("========================================");
      Serial.println("Matter Commissioning Data");
      Serial.println("========================================");
      Serial.print("QR URL     : ");
      Serial.println(qrUrl);
      Serial.print("QR Payload : ");
      Serial.println(qrPayload);
      Serial.println("Manual Code: 3497-025-9332");
      Serial.println("========================================");
      Serial.println();

      drawOnboardQRCode(qrPayload.c_str());
    } else {
      updateOLEDUI();
    }

    for (int i = 0; i < 4; i++) {
      logAndSwitch(i, relayStates[i], "BOOT-SYNC");
    }
  }

  if (bootSyncCompleted) {
    updateNetworkStatusLED();

    if (currentMillis - lastNetworkPollTime >= networkPollInterval) {
      lastNetworkPollTime = currentMillis;

      bool mState1 = matterRelay1.get_onoff();
      bool mState2 = matterRelay2.get_onoff();
      bool mState3 = matterRelay3.get_onoff();
      bool mState4 = matterRelay4.get_onoff();

      bool changeDetected = false;

      if (mState1 != shadowMatterStates[0]) {
        shadowMatterStates[0] = mState1;
        logAndSwitch(0, mState1, "REMOTE");
        changeDetected = true;
      }

      if (mState2 != shadowMatterStates[1]) {
        shadowMatterStates[1] = mState2;
        logAndSwitch(1, mState2, "REMOTE");
        changeDetected = true;
      }

      if (mState3 != shadowMatterStates[2]) {
        shadowMatterStates[2] = mState3;
        logAndSwitch(2, mState3, "REMOTE");
        changeDetected = true;
      }

      if (mState4 != shadowMatterStates[3]) {
        shadowMatterStates[3] = mState4;
        logAndSwitch(3, mState4, "REMOTE");
        changeDetected = true;
      }

      if (changeDetected) {
        updateOLEDUI();
      }
    }

    if (currentMillis - lastNetworkCheckTime >= networkCheckInterval) {
      lastNetworkCheckTime = currentMillis;
      updateOLEDUI();
    }

    for (int i = 0; i < 4; i++) {
      if (buttonFlags[i]) {
        buttonFlags[i] = false;

        bool nextState = !relayStates[i];
        shadowMatterStates[i] = nextState;

        logAndSwitch(i, nextState, "LOCAL SWITCH");

        if (i == 0) matterRelay1.set_onoff(nextState);
        if (i == 1) matterRelay2.set_onoff(nextState);
        if (i == 2) matterRelay3.set_onoff(nextState);
        if (i == 3) matterRelay4.set_onoff(nextState);
      }
    }
  }

  if (digitalRead(BTN_BUILTIN) == LOW) {
    unsigned long startTime = millis();

    oled.clear();
    oled.println("WIPING MEMORY...");

    while (digitalRead(BTN_BUILTIN) == LOW) {
      if ((millis() - startTime) / 1000 >= 10) {
        Matter.decommission();
        delay(1000);
        NVIC_SystemReset();
        break;
      }

      digitalWrite(LEDR, !digitalRead(LEDR));
      delay(100);
    }

    digitalWrite(LEDR, HIGH);
    updateOLEDUI();
  }
}
